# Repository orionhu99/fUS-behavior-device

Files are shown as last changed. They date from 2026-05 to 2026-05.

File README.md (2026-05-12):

# Head-fixed fUS behavior device control

整合式头部固定小鼠行为实验控制装置，兼容单光子/双光子/fUS 成像。

核心功能：
- **Cue-给水同步协议**：8kHz cue（PC 3.5mm 音响）+ 给水同时触发 → 2s 舔水窗 → 舔即记录 / 超时 MISS → 随机 ITI
- **电容舔水检测**（MPR121），直接寄存器读写，MDEBUG/THR 命令可调灵敏度
- **TTL 输出**：reward / lick / sync，对接成像采集系统
- **USB 摄像头录像 + 帧时间戳**，预览/录像独立切换，协议运行时自动录像
- **模块化水嘴支架**，预留食槽替换接口
- **PC 端 GUI**：参数设置、协议控制、时间轴舔水图表、事件日志

## File layout

```
arduino/
  water_lick_ttl_controller/water_lick_ttl_controller.ino  ← Water Nano 固件
  spout_motor_controller/spout_motor_controller.ino        ← Motor Nano 固件
  dianji/dianji.ino                                        ← 旧版电机测试（参考）
  sketch_apr25b/sketch_apr25b.ino                          ← 旧版给水测试（参考）
bpod/
  ExternalCueHiFi8kHz/ExternalCueHiFi8kHz.m                ← Bpod HiFi cue 协议
python/
  device_control_app.py     ← 主应用入口
  protocol_engine.py        ← 试次状态机
  gui_panels.py             ← GUI 面板组件
  lick_plot.py              ← matplotlib 舔水时间线
  config_manager.py         ← 协议配置 JSON 读写
  requirements.txt
  protocol_configs/         ← 保存的协议配置文件
      default.json
*.SLDPRT / *.STL / *.STEP  ← 3D 打印模型文件
```

## 给水协议

### 流程

```
IDLE → (▶ 运行) → ITI → PRECUE(200ms) → CUE(80ms, 8kHz) → 舔水窗口(3s)
                                                               ├─ 舔水 → 立即给水(400ms) → POST_REWARD(500ms) → ITI
                                                               └─ 超时 → 跳过(MISS) → ITI
```

- **Cue**：Water Nano D11 脉冲 TTL → Bpod BNC1 → HiFi 模块播放 8kHz tone
- **舔水窗口**：Nano 收到 `WINDOW dur reward` 命令后自治执行——监测 MPR121，舔到立即开泵，超时则跳过
- 关键延迟路径（舔→给水）在 Nano 上本地完成，不经 USB

### 可调参数

| 参数 | 默认值 | 说明 |
|---|---|---|
| `cue_duration_ms` | 80 | 8kHz 声音时长 |
| `precue_ms` | 200 | cue 前静默期（设 0 跳过） |
| `window_duration_ms` | 3000 | 舔水检测时间窗 |
| `reward_dose_ms` | 400 | 泵运行时长 |
| `post_reward_ms` | 500 | 给水后消耗期 |
| `iti_min_s` / `iti_max_s` | 20 / 60 | ITI 均匀随机范围 |
| `max_trials` | 200 | 最大试次数（0=不限） |
| `session_timeout_s` | 3600 | 最长会话时长 |

所有参数通过 GUI 调整，可保存/加载为 JSON 配置文件。

---

## Serial commands

### Water Nano

```
WATER [ms]           → 手动给水（含 reward TTL + cue TTL）
DOSE ms              → 设定默认剂量
PUMP ON / OFF        → 泵持续开/关
STOP                 → 停止泵 + 取消窗口模式
TTLMS ms             → 设定 TTL 脉宽
SYNCMS ms            → 设定同步脉冲间隔
CUE                  → 仅脉冲 D11 cue TTL（不启动泵）
WINDOW dur reward    → 启动舔水自治窗口（dur=窗口时长ms, reward=给水量ms）
WINDOW_STOP          → 取消当前窗口
STATUS / HELP
```

### Motor Nano（不变）

```
STEP signed_steps    GOTO position       F / B
JOG F / JOG B        STOP
ENABLE / DISABLE     SPEED microseconds
ZERO                 STATUS / HELP
```

---

## 接线（完整）

---

### 系统接线总览

```
┌─────────────────────────────────────────────────────────────────────────┐
│                               PC (USB Hub)                              │
│  USB1: Water Nano  │  USB2: Motor Nano  │  USB3: Bpod  │  USB4: 摄像头  │
└────┬──────────┬────┴──────────┬─────────┴──────┬───────┴──────┬────────┘
     │          │               │                │              │
┌────▼──┐  ┌────▼──────────┐  ┌▼─────────┐  ┌───▼──────┐  ┌───▼───┐
│ Water │  │   Motor Nano  │  │   Bpod   │  │  USB 摄  │  │ 水瓶  │
│ Nano  │  │               │  │  + HiFi  │  │  像头   │  │       │
│       │  │               │  │          │  │          │  │   │   │
│ D2─按钮│  │ D2─STEP─驱动板│  │ BNC1◄───┼──┼─D11(Cue) │  │   │   │
│ D3─LED │  │ D3─DIR──驱动板│  │     ┌───┼──┼─D8 (Rew) │  │   │   │
│ D5─MOS─┼──┼─蠕动泵       │  │ HiFi┼音响│  │ D9 (Lick)│  │  硅胶管─┤
│ D8─BNC─┼──┼─成像系统     │  │     │   │  │ D10(Sync)│  │       │   │
│ D9─BNC─┼──┼─成像系统     │  │     │   │  │          │  │   ┌───▼──┐│
│ D10─BNC┼──┼─成像系统     │  └─────┘   │  └──────────┘  │   │蠕动泵││
│ D11────┼──┼─Bpod BNC1   │            │               │   └──┬───┘│
│ A4─SDA─┼──┼─MPR121      │            │               │      │    │
│ A5─SCL─┼──┼─MPR121      │            │               │  外部电源 │
│        │  │             │            │               └──────────┘
│ 3V3/GND│  │ D4─ENA─驱动板│
│   ┤    │  │             │          ┌──────────────┐
│ MPR121 │  │ 5V/GND──驱动板│          │ 成像采集系统  │
│  E0    │  │             │          │ BNC Inputs:  │
│  ┤     │  │ 电机电源──驱动板│          │  Rew  Lick  │
│ 舔水管 │  │ 电机A/B──步进电机│         │  Sync Cue   │
└────────┘  └──────┬──────┘          └──────────────┘
                   │
              ┌────▼────┐
              │ 步进电机 │
              │ + 滑台  │
              └────┬────┘
                   │
              ┌────▼────┐
              │ 水嘴支架 │
              │(模块化) │
              └─────────┘
```

---

### 一、Water Nano 接线

Water Nano 是主控，负责蠕动泵、舔水检测、所有 TTL 输出。**在 Arduino IDE 中刷入 `arduino/water_lick_ttl_controller/` 固件。**

#### 1.1 引脚全表

| Nano 引脚 | 方向 | 连接到 | 线材 | 备注 |
|---|---|---|---|---|
| **D2** | 输入 (INPUT_PULLUP) | 轻触按钮一端，按钮另一端接 GND | 杜邦线 2P | 手动触发给水 |
| **D3** | 输出 | LED 正极（串 220Ω 电阻），LED 负极接 GND | 杜邦线 | 泵运行指示 |
| **D5** | 输出 | 三极管基极（串 1kΩ 电阻）或 MOSFET SIG 端 | 杜邦线 | 泵开关信号（HIGH=开） |
| **D8** | 输出 | BNC 母座中心针（Reward TTL） | 屏蔽线/杜邦线 | → 成像采集系统 |
| **D9** | 输出 | BNC 母座中心针（Lick TTL） | 屏蔽线/杜邦线 | → 成像采集系统 |
| **D10** | 输出 | BNC 母座中心针（Sync TTL） | 屏蔽线/杜邦线 | → 成像采集系统 |
| **D11** | 输出 | Bpod BNC1 中心针 | 屏蔽线/杜邦线 | Cue TTL → Bpod |
| **A4 / SDA** | I2C | MPR121 SDA 引脚 | 杜邦线母-母 | I2C 数据 |
| **A5 / SCL** | I2C | MPR121 SCL 引脚 | 杜邦线母-母 | I2C 时钟 |
| **5V** | 电源输出 | MPR121 VIN（若用 5V 供电版本） | 杜邦线 | 或接 3.3V |
| **3.3V** | 电源输出 | MPR121 VCC（推荐） | 杜邦线 | 噪声更小 |
| **GND** | 共地 | **所有以下设备的 GND**：MPR121、MOSFET 模块、BNC 外壳、Bpod GND | 多股杜邦线 | **最关键的单根线** |
| **VIN / USB** | 电源输入 | PC USB 口（供电 + 串口通信） | USB Mini-B 线 | 直接用 USB 供电即可 |

#### 1.2 手动按钮接线

```
Nano D2 ────┬──── 轻触按钮 ──── GND
            │
        (内部 INPUT_PULLUP，无需外接上拉电阻)
```

线序：D2 → 按钮一脚，按钮另一脚 → Nano GND。按下时 D2 读到 LOW，松开读到 HIGH。

#### 1.3 状态 LED 接线

```
Nano D3 ──── 220Ω 电阻 ──── LED 正极（长脚）
LED 负极（短脚） ──── Nano GND
```

#### 1.4 蠕动泵驱动 —— 方式 A：NPN 三极管（推荐，简单可靠）

```
        5V ───────────── 蠕动泵 +
        Nano D5 ── 1kΩ ── 三极管 Base (如 S8050 / 2N2222)
        蠕动泵 - ──────── 三极管 Collector
        Nano GND ─────── 三极管 Emitter

        三极管引脚（TO-92 封装，平面朝自己，脚朝下）：
                  ┌─────┐
        Collector │  ·  │  ← 接泵-
           Base   │  ·  │  ← 接 1kΩ → D5
         Emitter  │  ·  │  ← 接 GND
                  └─────┘
```

- D5 HIGH → 三极管导通 → 泵运转
- D5 LOW → 三极管截止 → 泵停止
- 泵两端反向并联一个 1N4007 续流二极管（带环一端接泵+，另一端接泵-），防止关断时反向电压击穿三极管
- 三极管选型：泵电流 < 500mA 用 S8050 即可；更大电流用 TIP120 达林顿管

#### 1.4 蠕动泵驱动 —— 方式 B：MOSFET 模块

```
┌─────────────┐
│  外部电源    │      注意：泵的电压/电流不要超过
│  (如 12V)   │      MOSFET 模块的额定值
│  +      -   │
│  │      │   │
│  │      └───┼──────────────┐
│  │          │              │
│  │    ┌─────▼──────┐      │
│  │    │ MOSFET 模块 │      │
│  │    │  DC+   DC- │      │
│  │    │  IN   GND  │      │
│  │    │  OUT+ OUT- │      │
│  │    └──┬───┬──┬──┘      │
│  │       │   │  │         │
│  └───────┼───┘  │         │
│          │      │         │
│    ┌─────▼──────┼──┐      │
│    │  蠕动泵     │  │      │
│    │   +    -   │  │      │
│    │   │    │   │  │      │
│    │   │    └───┼──┘      │
│    │   │        │         │
│    └───┼────────┘         │
│        │                  │
└────────┘                  │
                            │
    Nano D5 ──── IN         │
    Nano GND ─── GND ───────┘
```

接线步骤：
1. 外部电源 + 接 MOSFET 模块 DC+
2. 外部电源 - 接 MOSFET 模块 DC-
3. 蠕动泵 + 接 MOSFET 模块 OUT+
4. 蠕动泵 - 接 MOSFET 模块 OUT-
5. Nano D5 接 MOSFET 模块 IN（信号输入端）
6. **Nano GND 接 MOSFET 模块 GND（必须共地）**

> ⚠️ 泵是感性负载，关断时会产生反向电动势。如果 MOSFET 模块不带保护二极管，在泵两端并联一个续流二极管（如 1N4007）：阴极（带环一端）接泵+，阳极接泵-。

---

### 二、MPR121 电容舔水检测接线

#### 2.1 MPR121 → Water Nano

```
MPR121 VCC  ──── Nano 3.3V  （推荐 3.3V，噪声更低）
MPR121 GND  ──── Nano GND
MPR121 SDA  ──── Nano A4
MPR121 SCL  ──── Nano A5
MPR121 ADD  ──── 不接（默认 I2C 地址 0x5A）
MPR121 IRQ  ──── 不接（固件用轮询方式）
MPR121 E0   ──── 金属舔水管（见下方隔离说明）
```

#### 2.2 MPR121 电极隔离（最关键！）

```
┌──────────────────────────────────────────────────┐
│                  3D 打印支架                      │
│                                                  │
│   ┌──────────────────────────────┐              │
│   │  PTFE 绝缘套管（包住水管）     │              │
│   │  ┌────────────────────┐      │              │
│   │  │  金属舔水管（不锈钢）│      │              │
│   │  │  █████████████████ │      │              │
│   │  │  █████████████████ │      │              │
│   │  └──────────┬─────────┘      │              │
│   │             │ 仅管尖 1−2mm    │              │
│   │             │ 暴露供舔舐      │              │
│   └─────────────┼────────────────┘              │
│                 │                                │
│       MPR121 E0 ┘  (焊接或屏蔽线夹紧)              │
│                                                  │
│   水管全程不得与支架/电机/Z台/平台有金属接触        │
└──────────────────────────────────────────────────┘
```

操作步骤：
1. 截一段 PTFE 管（外径略小于支架孔），长度略长于支架厚度
2. 将 PTFE 管套在不锈钢水管外面，穿过 3D 打印支架孔
3. 不锈钢水管管体包覆热缩管，加热收缩，仅留管尖 1-2mm 裸露
4. MPR121 E0 引脚焊接一段细导线（或屏蔽线内芯），另一端用导电胶/焊锡/鳄鱼夹连接到不锈钢水管
5. 用万用表电阻档确认：水管与光学平台/电机外壳/支架之间的电阻 > 10MΩ（无穷大）

> 如果漏电（水管和大地导通），MPR121 会读到大量噪声，舔水检测失效。**这步做不好，整个系统不能用。**

---

### 三、Motor Nano 接线

Motor Nano 控制安装在手动 Z 台上的步进电机，用于微调水嘴位置。**在 Arduino IDE 中刷入 `arduino/spout_motor_controller/` 固件。**

#### 3.1 引脚全表

| Nano 引脚 | 方向 | 连接到 | 线材 | 备注 |
|---|---|---|---|---|
| **D2** | 输出 | 驱动板 STEP- (或 PUL-) | 杜邦线 | 步进脉冲 |
| **D3** | 输出 | 驱动板 DIR- | 杜邦线 | 方向信号 |
| **D4** | 输出 | 驱动板 ENA- | 杜邦线 | 使能（低电平有效） |
| **5V** | 电源输出 | 驱动板 STEP+/DIR+/ENA+ | 杜邦线 3 根 | **仅光耦驱动板需此接法** |
| **GND** | 共地 | 驱动板信号 GND（如有） | 杜邦线 | 非光耦驱动板需共地 |
| **VIN / USB** | 电源输入 | PC USB 口（供电 + 串口通信） | USB Mini-B 线 | |

#### 3.2 步进电机驱动板接线 —— 方式 A：光耦输入驱动板（如 TB6600 / DM542 / DM556）

这些驱动板的信号输入是光耦隔离的，推荐**共阳极接法**：

```
        Nano 5V ───┬─── 驱动板 PUL+  ┐
                    ├─── 驱动板 DIR+   │ 三个正端全部接 Nano 5V
                    └─── 驱动板 ENA+  ┘

        Nano D2 ─────── 驱动板 PUL-
        Nano D3 ─────── 驱动板 DIR-
        Nano D4 ─────── 驱动板 ENA-

        外部电源 + ───── 驱动板 VCC（电机电源输入，如 24V）
        外部电源 - ───── 驱动板 GND

        驱动板 A+ ────── 步进电机 A+（通常红色）
        驱动板 A- ────── 步进电机 A-（通常蓝色）
        驱动板 B+ ────── 步进电机 B+（通常绿色）
        驱动板 B- ────── 步进电机 B-（通常黑色）
```

> 注意：共阳接法时 Nano GND **不需要**接驱动板信号 GND。驱动板的信号地和功率地通常内部隔离。

#### 3.3 步进电机驱动板接线 —— 方式 B：普通逻辑输入驱动板（如 A4988 / DRV8825 / TMC2208）

```
        驱动板 VDD  ───── Nano 5V
        驱动板 GND  ───── Nano GND

        驱动板 STEP ───── Nano D2
        驱动板 DIR  ───── Nano D3
        驱动板 ENABLE ─── Nano D4

        驱动板 VMOT ───── 外部电源 +
        驱动板 GND  ───── 外部电源 -

        驱动板 1A ─────── 步进电机 A+
        驱动板 1B ─────── 步进电机 A-
        驱动板 2A ─────── 步进电机 B+
        驱动板 2B ─────── 步进电机 B-
```

> 固件默认 `enableActiveLow = true`。如果你的驱动板是高电平使能（如某些 TMC 系列），打开 `.ino` 文件把第 8 行改成 `const bool enableActiveLow = false;`。

---

### 四、TTL 信号输出接线

Water Nano 的 D8/D9/D10/D11 输出 5V TTL 脉冲。需要接到成像系统或用 BNC 接口标准化。

#### 4.1 TTL → BNC 母座（接成像系统）

自制 BNC 转接线（每路 TTL 做一根）：

```
Nano D8/D9/D10/D11 ──────── BNC 母座中心针（信号）
Nano GND           ──────── BNC 母座外壳/屏蔽层（地）
```

做法：
1. 取一段同轴电缆或双绞屏蔽线
2. 内芯一端接 Nano 排针（用杜邦母头压接或焊接），另一端焊 BNC 母座中心针
3. 屏蔽层一端接 Nano GND，另一端焊 BNC 母座外壳
4. BNC 母座固定在 3D 打印面板或铝盒上，用 BNC 公-公线连到成像系统

#### 4.2 TTL 信号分工

| Nano 引脚 | 事件 | 脉冲宽度 | 目标设备 |
|---|---|---|---|
| **D8** | Reward（给水开始） | `ttlPulseMs` (默认 10ms) | 成像系统 AI 通道 1 |
| **D9** | Lick（舔水） | `ttlPulseMs` (默认 10ms) | 成像系统 AI 通道 2 |
| **D10** | Sync（同步） | `ttlPulseMs` (默认 10ms) | 成像系统 AI 通道 3 |
| **D11** | Cue（8kHz 触发） | `ttlPulseMs` (默认 10ms) | Bpod BNC1 输入 |

> 成像系统如果是 BNC 接口，直接对接。如果是 DAQ 端子排（如 NI 68-Pin），做 BNC→端子排转接线。

#### 4.3 TTL 电平兼容性

- Nano 输出 5V TTL，兼容 3.3V 和 5V 逻辑
- Bpod r2/r2+ BNC 输入接受 3-5V TTL，光隔离，直接可接
- 如果目标设备只接受 3.3V：在信号线上串 1kΩ 限流电阻 + 对地接 3.3V 稳压管

---

### 五、Bpod + HiFi 模块接线

#### 5.1 Bpod → PC

```
Bpod USB-B ──── PC USB 口（供电 + MATLAB 通信）
```

#### 5.2 HiFi 模块 → Bpod

```
HiFi 模块 ──── Bpod 机箱背面模块接口（通过扁平排线或专用接口）
```

> 在 Bpod Console GUI 中确认模块识别为 `HiFi1`，USB 端口号写入 `BpodSystem.ModuleUSB.HiFi1`。

#### 5.3 HiFi 模块 → 音响

```
HiFi 模块音频输出 (3.5mm 或 RCA) ──── 有源音箱 Line In
```

> 使用有源音箱（自带功放）。如果只有无源音箱，中间需要加功放模块。HiFi 模块输出是线路电平，直接推不动无源音箱。

#### 5.4 Bpod BNC1 输入 ← Water Nano Cue TTL

```
Water Nano D11 ──── BNC 中心针 ──── Bpod BNC1 输入
Water Nano GND ──── BNC 外壳     ──── Bpod GND（如 BNC 外壳已内部接地则不必额外接）
```

#### 5.5 运行 Bpod 端

在 MATLAB 中：
```matlab
cd('D:\Research\fUS\device\bpod\ExternalCueHiFi8kHz')
ExternalCueHiFi8kHz
```

Bpod 会进入等待状态，每次 Water Nano D11 发来 TTL 脉冲，HiFi 就播放 80ms 的 8kHz tone。

---

### 六、USB 摄像头接线

```
USB 摄像头 ──── PC USB 口
```

- 在 GUI "连接"面板中输入摄像头索引（通常是 `0`，如有多个摄像头试 `1`、`2`）
- 点击"开始录像"即开始录制并生成帧时间戳 CSV
- 摄像头对准小鼠侧面/正面，记录舔水和行为

---

### 七、PC 端最终连接汇总

| 设备 | 接口 | PC 端口 |
|---|---|---|
| Water Nano | USB Mini-B | USB 1 |
| Motor Nano | USB Mini-B | USB 2 |
| Bpod | USB-B | USB 3 |
| USB 摄像头 | USB-A | USB 4 |

> 建议用一个 **有源 USB 3.0 Hub**（4 口以上），固定在光学平台边缘，只出一根线到 PC。减少桌面杂乱。

---

### 八、电源分配

| 用电设备 | 供电方式 | 电压 | 备注 |
|---|---|---|---|
| Water Nano | PC USB | 5V | 同时通信 |
| Motor Nano | PC USB | 5V | 同时通信 |
| MPR121 | Water Nano 3.3V | 3.3V | Nano 直接供电 |
| 蠕动泵 | 外部电源 → MOSFET | 12V（视泵规格） | **不要从 Nano 取电** |
| 步进电机 | 外部电源 → 驱动板 | 12-24V（视电机/驱动板） | **不要从 Nano 取电** |
| 步进驱动板逻辑 | Nano 5V（光耦型） | 5V | 电流很小 |
| Bpod | 自带电源适配器 | — | 官配 |
| 有源音箱 | 自带电源/USB | — | |

> 建议用一个双路输出开关电源（如 24V/12V 双路），或两个独立电源适配器分别给蠕动泵和步进电机供电。

---

### 九、上电顺序

1. 检查所有接线（特别确认：泵和电机的供电**没有**接到 Nano）
2. MPR121 隔离用万用表确认（水管对地电阻无穷大）
3. 打开蠕动泵和步进电机的外部电源
4. 打开 Bpod 电源
5. 所有 USB 插入 PC（或 USB Hub 上电）
6. 打开有源音箱，音量调至适中
7. 在 Arduino IDE 中确认两个 Nano 都识别到正确的 COM 口
8. 启动 Bpod MATLAB 协议 `ExternalCueHiFi8kHz`
9. 启动 Python GUI `python python\device_control_app.py`
10. 在 GUI 中依次连接 Water Nano 和 Motor Nano
11. 连接成功后，先用手动模式测试：手动给水确认泵和 TTL 正常，电机微调确认运动正常
12. 一切正常后，加载协议配置，点击 ▶ 运行

---

### 十、接地策略

```
                    ┌─── 光学平台（金属）─── 接大地（如有）
                    │
    ┌───────────────┼────────────────────────┐
    │               │                        │
    │  Water Nano GND ─┬─ MPR121 GND         │
    │                  ├─ MOSFET 模块 GND     │
    │                  ├─ BNC 外壳 (x4)      │
    │                  └─ Bpod BNC 外壳      │
    │                                        │
    │  Motor Nano GND ─── 驱动板信号 GND      │
    │  （光耦型驱动板则无需）                  │
    │                                        │
    │  外部电源 - ──┬─ MOSFET DC-            │
    │              └─ 驱动板功率 GND          │
    │                                        │
    │  所有设备通过 USB 电缆屏蔽层在 PC 端单点共地 │
    └────────────────────────────────────────┘
```

> 接地原则：所有信号 GND（Nano、MPR121、MOSFET 信号侧、TTL 目标设备）必须连通。不要形成地环路——在 PC USB 端单点汇聚即可。如果出现 50Hz 工频干扰在 MPR121 上，检查是否有多点接地。

---

## PC 端使用

### 安装

```powershell
pip install -r python\requirements.txt
```

### 运行

```powershell
python python\device_control_app.py
```

### GUI 面板

| 面板 | 功能 |
|---|---|
| 连接 | COM 端口选择、Nano 连接、摄像头控制、输出目录 |
| 手动控制 | 剂量设定、手动给水、泵开关、TTL/同步参数、PC 测试音 |
| 电机控制 | 大小步进微调、速度设定、归零 |
| 协议控制 | 全部协议参数、运行/暂停/停止、配置保存加载、状态显示 |
| 舔水时间线 | 实时试次栅格图 + 累积直方图 |
| 事件日志 | 所有串口事件 + 主机时间戳 |

### 输出文件

```
recordings/
  device_events_*.csv        ← 全事件日志（串口 + 主机）
  behavior_*.avi             ← 摄像头视频
  behavior_*_frames.csv      ← 视频帧时间戳
```

---

## 8kHz Cue 声音

**主方案**：PC 3.5mm 音频口 → 有源音箱。协议进入 CUE 阶段时自动播放 8kHz 纯音（WAV 生成 + winsound 播放），无需 Bpod/HiFi 模块。

手动测试：GUI "手动控制" 面板勾选 "PC 8kHz"，点"给水"时同步播放 cue 音。

> 如需 Bpod/HiFi 方案（更低延迟），D11 cue TTL 仍然保留，可接 Bpod BNC1 输入，运行 `bpod/ExternalCueHiFi8kHz/ExternalCueHiFi8kHz.m`。PC 音频和 TTL cue 可同时工作互不冲突。

---

## 时间对齐

**推荐方案：纯 USB 软件时间戳（±5ms，一帧以内）**

events.csv 中每条事件和 video_frames.csv 中每帧都有 `host_monotonic_s`（`time.perf_counter()`），两者统一时间轴对齐。

数据目录结构：
```
data/20260512_143000/
  events.csv          ← 所有事件 + host_monotonic_s
  video.avi           ← 摄像头录像
  video_frames.csv    ← 每帧时间戳
  session.json        ← 协议参数 + 试次汇总
```

**可选方案：物理 TTL 同步**

如需硬件级同步，Nano D8( Reward ) / D9( Lick ) / D10( Sync ) 通过 BNC 接入成像系统数字输入。Sync 每 5s 脉冲一次。

---

## 3D 打印件

| 零件 | 文件 | 说明 |
|---|---|---|
| 散热风扇导管 | `tube-fan3.0-4.3.STL` | |
| 动物固定兜 | `兜子.STEP` | 头部固定小鼠 |
| 给水外壳 | `给水1.0外壳.SLDPRT` | 电子盒外壳 |
| 水嘴模块底板（待设计） | — | 安装于电机滑台，带燕尾槽快拆接口 |
| 水嘴支架模块（待设计） | — | PTFE 绝缘套管、可调角度、快拆锁紧 |
| 食槽模块（预留接口） | — | 同底板燕尾槽规格 |

---

## 硬件清单

| 组件 | 说明 |
|---|---|
| PC (Windows) | USB 接口 ×4+ |
| Arduino Nano ×2 | Water + Motor |
| MPR121 电容模块 | I2C 接口，Adafruit 库 |
| 蠕动泵 + MOSFET 驱动 | 外部电源供电 |
| 步进电机 + 驱动板 | TB6600/DM 系列 |
| 手动 Z 台 + 电机滑台 | 水嘴微调 |
| 有源音箱 | PC 3.5mm 音频口连接 |
| Bpod + HiFi 模块（可选） | 低延迟 cue 播放备选 |
| USB 摄像头 | OpenCV 兼容 |
| 光学平台 | 面包板，M6 或 1/4"-20 孔距 |
| 3D 打印件 | 如上表 |
| 金属舔水管 | 不锈钢，与支架绝缘 |
| PTFE 管 / 热缩管 | MPR121 隔离 |
| BNC 线 / 杜邦线 | TTL 连接 |
| 硅胶管 / 水瓶 | 水路 |

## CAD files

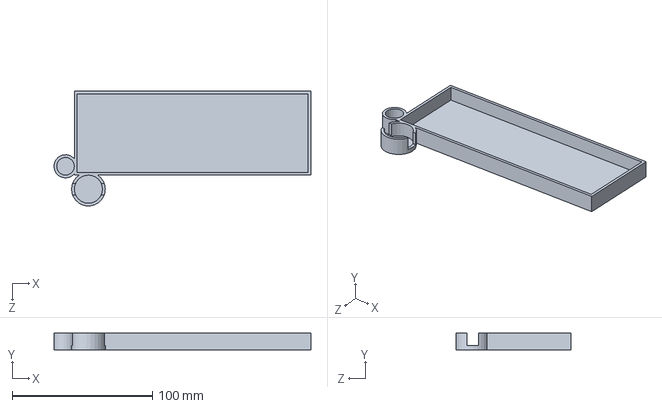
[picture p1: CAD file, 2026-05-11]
给水1.0外壳.SLDPRT
183.5 x 12.0 x 82.0 mm

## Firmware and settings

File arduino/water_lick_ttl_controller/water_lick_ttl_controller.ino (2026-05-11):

#include <Wire.h>
#include <avr/wdt.h>

// Nano for water delivery, lick detection, and TTL event outputs.

const byte buttonPin = 2;
const byte ledPin = 3;
const byte pumpPin = 5;

const byte rewardTtlPin = 8;
const byte lickTtlPin = 9;
const byte syncTtlPin = 10;
const byte cueTtlPin = 11;

const byte lickElectrode = 0;

// ── 参数 ──
unsigned long doseMs = 400;
unsigned long ttlPulseMs = 10;
unsigned long lickRefractoryMs = 100;
unsigned long syncIntervalMs = 5000;

// ── MPR121 灵敏度（运行时可调）──
byte mprTouchThr = 8;     // 触摸阈值，越小越灵敏（范围 1-255，默认 12）
byte mprReleaseThr = 4;   // 释放阈值，应小于触摸阈值（默认 6）
int confirmDeltaMin = 5;  // 软件确认：abs(baseline-filtered) 最小变化量

// ── 状态 ──
bool pumpRunning = false;
bool autoMode = false;

// MPR121
byte mprAddr = 0x5A;
bool mpr121Ready = false;

// 舔水检测
bool lastTouched = false;
bool lickLatched = false;
unsigned long lastLickAt = 0;
unsigned long lastReleaseAt = 0;
unsigned long lickReleaseMs = 100;
int confirmCnt = 0;

// 窗口模式
bool windowMode = false;
unsigned long windowStartAt = 0;
unsigned long windowDurationMs = 0;
unsigned long windowRewardMs = 0;
bool windowRewarded = false;

// 计时
unsigned long pumpStopAt = 0;
unsigned long nextSyncAt = 0;
unsigned long rewardTtlOffAt = 0;
unsigned long lickTtlOffAt = 0;
unsigned long syncTtlOffAt = 0;
unsigned long cueTtlOffAt = 0;

char line[64];
byte lineIdx = 0;

// ═══════════════════════════════════════════════════════════
// MPR121 底层读写（绕过 Adafruit 库）
// ═══════════════════════════════════════════════════════════

static unsigned long lastMprRead = 0;
static bool i2cOk = true;

bool mprWrite(byte reg, byte val) {
  Wire.beginTransmission(mprAddr);
  Wire.write(reg);
  Wire.write(val);
  byte r = Wire.endTransmission();
  if (r != 0) { i2cOk = false; return false; }
  i2cOk = true; return true;
}

byte mprRead8(byte reg) {
  Wire.beginTransmission(mprAddr);
  Wire.write(reg);
  if (Wire.endTransmission(false) != 0) { i2cOk = false; return 0; }
  Wire.requestFrom((uint8_t)mprAddr, (uint8_t)1);
  byte v = Wire.available() ? Wire.read() : 0;
  i2cOk = true; return v;
}

uint16_t mprRead16(byte reg) {
  Wire.beginTransmission(mprAddr);
  Wire.write(reg);
  if (Wire.endTransmission(false) != 0) { i2cOk = false; return 0; }
  Wire.requestFrom((uint8_t)mprAddr, (uint8_t)2);
  uint16_t v = 0;
  if (Wire.available()) v = Wire.read();
  if (Wire.available()) v |= ((uint16_t)Wire.read() << 8);
  i2cOk = true; return v & 0x03FF;
}

void i2cRecover() {
  Wire.end();
  delay(5);
  Wire.begin();
  delay(5);
  i2cOk = true;
}

// ═══════════════════════════════════════════════════════════
// MPR121 手动初始化（不依赖 Adafruit 库的 begin）
// ═══════════════════════════════════════════════════════════

bool initMpr121() {
  Serial.println(F("--- MPR121 manual init ---"));

  // 1. I2C 扫描
  Serial.println(F("I2C scan:"));
  int found = 0;
  for (byte a = 1; a < 127; a++) {
    Wire.beginTransmission(a);
    if (Wire.endTransmission() == 0) {
      Serial.print(F("  0x")); Serial.println(a, HEX);
      found++;
    }
  }
  if (found == 0) {
    Serial.println(F("!! No I2C devices — check VCC/GND/SDA/SCL wiring"));
    return false;
  }

  // 2. 尝试 MPR121 地址
  byte addrs[] = {0x5A, 0x5B, 0x5C, 0x5D};
  mprAddr = 0;
  for (byte i = 0; i < 4; i++) {
    Wire.beginTransmission(addrs[i]);
    if (Wire.endTransmission() == 0) { mprAddr = addrs[i]; break; }
  }
  if (mprAddr == 0) {
    Serial.println(F("!! MPR121 not found at 0x5A-0x5D"));
    return false;
  }
  Serial.print(F("MPR121 at 0x")); Serial.println(mprAddr, HEX);

  // 3. 软复位
  mprWrite(0x80, 0x63);
  delay(10);

  // 4. 停止，开始配置
  mprWrite(0x5E, 0x00);
  delay(5);

  // 5. AFE 配置（Analog Front End）
  mprWrite(0x2B, 0x01); // MHD Rising
  mprWrite(0x2C, 0x01); // NHD Rising
  mprWrite(0x2D, 0x00); // NCL Rising
  mprWrite(0x2E, 0x00); // FDL Rising
  mprWrite(0x2F, 0x01); // MHD Falling
  mprWrite(0x30, 0x01); // NHD Falling
  mprWrite(0x31, 0xFF); // NCL Falling
  mprWrite(0x32, 0x02); // FDL Falling

  // 6. 触摸/释放阈值 — 只设电极 0
  mprWrite(0x41, mprTouchThr);   // E0 触摸阈值
  mprWrite(0x42, mprReleaseThr); // E0 释放阈值

  // 7. 去抖
  mprWrite(0x5B, 0x00); // 去抖 = 0（由软件处理）

  // 8. 配置寄存器
  mprWrite(0x5C, 0x10); // Config1: FFI=1 (28ms 首滤波), CDC=0, SFI=0, ESI=0
  mprWrite(0x5D, 0x20); // Config2: 0.5uA 充电, 0.5us 充电时间

  // 9. 使能电极 0（仅 E0，开启基线自动追踪）
  //    ECR bit[3:0] = 电即使能 + 基线追踪
  //    ECR bit[7:4] = 接近检测使能（不用）
  mprWrite(0x5E, 0x01);

  delay(200);

  // 10. 校验：回读 ECR
  byte ecr = mprRead8(0x5E);
  Serial.print(F("ECR = 0x")); Serial.println(ecr, HEX);
  if (ecr != 0x01) {
    Serial.println(F("!! ECR mismatch — configuration failed"));
    return false;
  }

  // 11. 读初始值
  uint16_t f0 = mprRead16(0x04);
  uint16_t b0 = mprRead16(0x1E);
  Serial.print(F("E0 raw filtered=")); Serial.print(f0);
  Serial.print(F(" baseline=")); Serial.print(b0);
  Serial.print(F(" diff=")); Serial.println((int16_t)b0 - (int16_t)f0);

  if (f0 == 0 && b0 == 0) {
    Serial.println("!! filtered=0 AND baseline=0 -- electrode may be floating");
    Serial.println("   Check: MPR121 E0 pin -> metal lick tube");
    Serial.println("   Check: tube insulation with multimeter");
  }

  Serial.println(F("--- MPR121 init done ---"));
  Serial.println("Send MDEBUG for live values, REGDUMP for register dump");
  return true;
}

// ═══════════════════════════════════════════════════
// 初始化
// ═══════════════════════════════════════════════════

void setup() {
  pinMode(buttonPin, INPUT_PULLUP);
  pinMode(ledPin, OUTPUT);
  pinMode(pumpPin, OUTPUT);
  pinMode(rewardTtlPin, OUTPUT);
  pinMode(lickTtlPin, OUTPUT);
  pinMode(syncTtlPin, OUTPUT);
  pinMode(cueTtlPin, OUTPUT);

  setPump(false);
  setAllTtlsLow();

  Serial.begin(115200);
  while (!Serial) {}

  // 看门狗：500ms 超时自动复位（防止 I2C 卡死导致永久死机）
  wdt_enable(WDTO_500MS);

  mpr121Ready = initMpr121();

  logEvent("READY", mpr121Ready ? "MPR121_OK" : "MPR121_MISSING");
  printHelp();
}

// ═══════════════════════════════════════════════════
// 主循环
// ═══════════════════════════════════════════════════

void loop() {
  wdt_reset();  // 喂狗
  const unsigned long now = millis();
  readSerial();
  readButton();
  readLick(now);
  updatePump(now);
  updateTtls(now);
  updateSync(now);
  updateWindow(now);
}

// ═══════════════════════════════════════════════════
// 串口命令
// ═══════════════════════════════════════════════════

void readSerial() {
  while (Serial.available() > 0) {
    char c = (char)Serial.read();
    if (c == '\n' || c == '\r') {
      if (lineIdx > 0) {
        line[lineIdx] = '\0';
        handleCommand(line);
        lineIdx = 0;
      }
    } else if (lineIdx < 63) {
      line[lineIdx++] = c;
    }
  }
}

void handleCommand(const char* cmd) {
  // 跳过前导空格
  while (*cmd == ' ' || *cmd == '\t') cmd++;
  int len = strlen(cmd);
  if (len == 0) return;

  // 转大写
  char upper[64];
  for (int i = 0; i <= len; i++) upper[i] = (cmd[i] >= 'a' && cmd[i] <= 'z') ? cmd[i] - 32 : cmd[i];

  if (strcmp(upper, "HELP") == 0)             printHelp();
  else if (strcmp(upper, "STATUS") == 0)      logEvent("STATUS", statusText());
  else if (strcmp(upper, "WATER") == 0)       startDose(doseMs);
  else if (strncmp(upper, "WATER ", 6) == 0)  startDose(atol(upper + 6));
  else if (strncmp(upper, "DOSE ", 5) == 0)   { doseMs = atol(upper + 5); logEvent("DOSE_MS", String(doseMs).c_str()); }
  else if (strcmp(upper, "PUMP ON") == 0)     { autoMode = true;  setPump(true);  logEvent("PUMP", "ON"); }
  else if (strcmp(upper, "PUMP OFF") == 0 || strcmp(upper, "STOP") == 0) {
    autoMode = false; pumpRunning = false; windowMode = false;
    setPump(false); logEvent("PUMP", "OFF");
  }
  else if (strcmp(upper, "CUE") == 0)         { pulseCueTtl(millis()); logEvent("CUE", "1"); }
  else if (strncmp(upper, "WINDOW ", 7) == 0) {
    char* sp1 = strchr(upper + 7, ' ');
    if (sp1) {
      windowDurationMs = atol(upper + 7);
      windowRewardMs = atol(sp1 + 1);
      windowMode = true; windowStartAt = millis(); windowRewarded = false;
      logEvent("WINDOW_START", (String(windowDurationMs) + "," + String(windowRewardMs)).c_str());
    }
  }
  else if (strcmp(upper, "WINDOW_STOP") == 0) { windowMode = false; logEvent("WINDOW_STOP", "0"); }
  else if (strncmp(upper, "TTLMS ", 6) == 0)  { ttlPulseMs = atol(upper + 6); logEvent("TTL_MS", String(ttlPulseMs).c_str()); }
  else if (strncmp(upper, "SYNCMS ", 7) == 0) { syncIntervalMs = atol(upper + 7); logEvent("SYNC_MS", String(syncIntervalMs).c_str()); }
  else if (strcmp(upper, "MDEBUG") == 0)      printMdebug();
  else if (strcmp(upper, "REGDUMP") == 0)     dumpRegisters();
  else if (strcmp(upper, "RESETMPR") == 0)    { mpr121Ready = initMpr121(); }
  else if (strncmp(upper, "THR ", 4) == 0) {
    char* sp = strchr(upper + 4, ' ');
    if (sp) {
      mprTouchThr = atoi(upper + 4);
      mprReleaseThr = atoi(sp + 1);
      mprWrite(0x41, mprTouchThr); mprWrite(0x42, mprReleaseThr);
      logEvent("THR", (String(mprTouchThr) + "," + String(mprReleaseThr)).c_str());
    }
  }
  else if (strncmp(upper, "DMIN ", 5) == 0)   { confirmDeltaMin = atoi(upper + 5); logEvent("DMIN", String(confirmDeltaMin).c_str()); }
  else                                         logEvent("ERR", "UNKNOWN_COMMAND");
}

// ── 诊断命令 ──

void printMdebug() {
  uint16_t f = mprRead16(0x04);
  uint16_t b = mprRead16(0x1E);
  uint8_t  t = mprRead8(0x00);
  int16_t diff = (int16_t)b - (int16_t)f;
  Serial.print(millis());
  Serial.print(F(",DEBUG,filtered=")); Serial.print(f);
  Serial.print(F(",baseline=")); Serial.print(b);
  Serial.print(F(",diff=")); Serial.print(diff);
  int16_t ad = (int16_t)b - (int16_t)f;
  if (ad < 0) ad = -ad;
  Serial.print(F(",touched=0x")); Serial.print(t, HEX);
  Serial.print(F(",thr=")); Serial.print(mprTouchThr);
  Serial.print(F(",dmin=")); Serial.println(ad >= confirmDeltaMin ? 1 : 0);
}

void dumpRegisters() {
  Serial.println(F("--- MPR121 register dump ---"));
  Serial.print(F("ECR(0x5E)=")); Serial.println(mprRead8(0x5E), HEX);
  Serial.print(F("CONF1(0x5C)=")); Serial.println(mprRead8(0x5C), HEX);
  Serial.print(F("CONF2(0x5D)=")); Serial.println(mprRead8(0x5D), HEX);
  Serial.print(F("TOUCH_STAT(0x00)=")); Serial.println(mprRead8(0x00), HEX);
  Serial.print(F("OOR_STAT(0x02)=")); Serial.println(mprRead8(0x02), HEX);
  Serial.print(F("E0_TOUCH_THR(0x41)=")); Serial.println(mprRead8(0x41));
  Serial.print(F("E0_REL_THR(0x42)=")); Serial.println(mprRead8(0x42));
  Serial.print(F("DEBOUNCE(0x5B)=")); Serial.println(mprRead8(0x5B), HEX);

  uint16_t f0 = mprRead16(0x04);
  uint16_t b0 = mprRead16(0x1E);
  Serial.print(F("E0 filtered=")); Serial.print(f0);
  Serial.print(F(" baseline=")); Serial.print(b0);
  Serial.print(F(" diff=")); Serial.println((int16_t)b0 - (int16_t)f0);

  // 读 CDC 原始计数（电极 0 的 CDC: 0x59-0x5A？）
  // 实际上是 0x04-0x05=filtered, 0x1E-0x1F=baseline
  Serial.println(F("--- end dump ---"));
}

// ═══════════════════════════════════════════════════
// 按钮
// ═══════════════════════════════════════════════════

void readButton() {
  static bool lastButton = HIGH;
  bool button = digitalRead(buttonPin);
  if (lastButton == HIGH && button == LOW) {
    startDose(doseMs);
  }
  lastButton = button;
}

// ═══════════════════════════════════════════════════
// 舔水检测
// ═══════════════════════════════════════════════════

void readLick(unsigned long now) {
  if (!mpr121Ready) return;

  // 降频：每 5ms 读一次（200Hz），防 I2C 总线风暴
  if (now - lastMprRead < 5) return;
  lastMprRead = now;

  // I2C 异常恢复
  if (!i2cOk) { i2cRecover(); return; }

  // 读 MPR121 寄存器（一次 3 字节批量读，减少 I2C 事务）
  uint8_t touchedReg = mprRead8(0x00);
  uint16_t filtered = mprRead16(0x04);
  uint16_t baseline = mprRead16(0x1E);
  if (!i2cOk) return;  // 本次读取失败则跳过

  bool hwTouched = touchedReg & 0x01;
  int16_t delta = (int16_t)baseline - (int16_t)filtered;
  int16_t adelta = delta < 0 ? -delta : delta;
  bool signalOk = adelta >= confirmDeltaMin;
  bool isTouched = hwTouched && signalOk;

  if (isTouched) confirmCnt++;
  else           confirmCnt = 0;
  bool confirmed = (confirmCnt >= 2);

  // 上升沿 → 触发舔水
  if (confirmed && !lastTouched && !lickLatched &&
      (now - lastLickAt >= lickRefractoryMs)) {
    lastLickAt = now;
    lickLatched = true;
    pulseLickTtl(now);
    logEvent("LICK", (String(lickElectrode)).c_str());
    if (windowMode && !windowRewarded) {
      startWindowReward(windowRewardMs);
      logEvent("WINDOW_LICK", (String(windowRewardMs)).c_str());
    }
  }

  // 释放检测
  if (!confirmed && lastTouched) lastReleaseAt = now;
  if (lickLatched && !confirmed && (now - lastReleaseAt >= lickReleaseMs))
    lickLatched = false;

  lastTouched = confirmed;
}

// ═══════════════════════════════════════════════════
// 给水
// ═══════════════════════════════════════════════════

void startDose(unsigned long ms) {
  if (ms == 0) return;
  unsigned long now = millis();
  autoMode = false;
  pumpRunning = true;
  pumpStopAt = now + ms;
  setPump(true);
  pulseRewardTtl(now);
  pulseCueTtl(now);
  logEvent("WATER", (String(ms)).c_str());
}

void startWindowReward(unsigned long ms) {
  if (ms == 0) return;
  unsigned long now = millis();
  windowRewarded = true;
  autoMode = false;
  pumpRunning = true;
  pumpStopAt = now + ms;
  setPump(true);
  pulseRewardTtl(now);
  logEvent("WINDOW_REWARD", (String(ms)).c_str());
}

// ═══════════════════════════════════════════════════
// 定时更新
// ═══════════════════════════════════════════════════

void updateWindow(unsigned long now) {
  if (!windowMode) return;
  if (!windowRewarded && timeReached(now, windowStartAt + windowDurationMs)) {
    windowMode = false; logEvent("WINDOW_END", "MISSED");
  }
  if (windowRewarded && !pumpRunning) {
    windowMode = false; logEvent("WINDOW_END", "REWARDED");
  }
}

void updatePump(unsigned long now) {
  if (pumpRunning && !autoMode && timeReached(now, pumpStopAt)) {
    pumpRunning = false; setPump(false); logEvent("WATER_END", "0");
  }
}

void updateSync(unsigned long now) {
  if (syncIntervalMs == 0) return;
  if (nextSyncAt == 0) nextSyncAt = now + syncIntervalMs;
  if (timeReached(now, nextSyncAt)) {
    digitalWrite(syncTtlPin, HIGH);
    syncTtlOffAt = now + ttlPulseMs;
    nextSyncAt += syncIntervalMs;
    // TTL 脉冲照发，但不打串口日志（减少刷屏）
  }
}

void updateTtls(unsigned long now) {
  if (rewardTtlOffAt && timeReached(now, rewardTtlOffAt)) { digitalWrite(rewardTtlPin, LOW); rewardTtlOffAt = 0; }
  if (lickTtlOffAt   && timeReached(now, lickTtlOffAt))   { digitalWrite(lickTtlPin, LOW);   lickTtlOffAt = 0; }
  if (syncTtlOffAt   && timeReached(now, syncTtlOffAt))   { digitalWrite(syncTtlPin, LOW);   syncTtlOffAt = 0; }
  if (cueTtlOffAt    && timeReached(now, cueTtlOffAt))    { digitalWrite(cueTtlPin, LOW);    cueTtlOffAt = 0; }
}

// ═══════════════════════════════════════════════════
// TTL 脉冲
// ═══════════════════════════════════════════════════

void pulseRewardTtl(unsigned long now) { digitalWrite(rewardTtlPin, HIGH); rewardTtlOffAt = now + ttlPulseMs; }
void pulseLickTtl(unsigned long now)   { digitalWrite(lickTtlPin, HIGH);   lickTtlOffAt   = now + ttlPulseMs; }
void pulseCueTtl(unsigned long now)    { digitalWrite(cueTtlPin, HIGH);    cueTtlOffAt    = now + ttlPulseMs; }

// ═══════════════════════════════════════════════════
// 泵 / LED
// ═══════════════════════════════════════════════════

void setPump(bool on) { digitalWrite(pumpPin, on ? HIGH : LOW); digitalWrite(ledPin, on ? HIGH : LOW); }

void setAllTtlsLow() {
  digitalWrite(rewardTtlPin, LOW); digitalWrite(lickTtlPin, LOW);
  digitalWrite(syncTtlPin, LOW);   digitalWrite(cueTtlPin, LOW);
}

// ═══════════════════════════════════════════════════
// 工具函数
// ═══════════════════════════════════════════════════

bool timeReached(unsigned long now, unsigned long target) { return (long)(now - target) >= 0; }

const char* statusText() {
  static char buf[80];
  snprintf(buf, sizeof(buf), "dose_ms=%lu,pump=%d,mpr121=%d,sync_ms=%lu",
           doseMs, digitalRead(pumpPin), mpr121Ready, syncIntervalMs);
  return buf;
}

void logEvent(const char* eventName, const char* value) {
  Serial.print(millis()); Serial.print(",");
  Serial.print(eventName); Serial.print(",");
  Serial.println(value);
}

void printHelp() {
  Serial.println(F("Commands: WATER [ms], DOSE ms, PUMP ON/OFF, STOP, TTLMS ms, SYNCMS ms,"));
  Serial.println(F("  CUE, WINDOW dur reward, WINDOW_STOP, MDEBUG, REGDUMP,"));
  Serial.println(F("  THR t r      (touch/release threshold, lower=more sensitive)"));
  Serial.println(F("  DMIN min     (software confirm delta, default 5)"));
  Serial.println(F("  RESETMPR     (re-init MPR121)"));
  Serial.println(F("  STATUS, HELP"));
}

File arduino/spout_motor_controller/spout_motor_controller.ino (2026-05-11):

// Nano for the motor mounted on the manual Z-stage water-spout module.
// The Z-stage itself is adjusted manually; this motor only drives the mounted
// spout/module mechanism.
// Keeps the original pins from your working sketch.

const byte stepPin = 2;
const byte dirPin = 3;
const byte enablePin = 4;
const bool enableActiveLow = false;

unsigned int stepDelayUs = 2000;
long positionSteps = 0;
long targetSteps = 0;
bool movingToTarget = false;
int jogDirection = 0;
unsigned long lastStepAt = 0;

String line;

void setup() {
  pinMode(stepPin, OUTPUT);
  pinMode(dirPin, OUTPUT);
  pinMode(enablePin, OUTPUT);
  digitalWrite(stepPin, LOW);
  digitalWrite(dirPin, LOW);
  setEnabled(true);

  Serial.begin(115200);
  while (!Serial) {}
  Serial.println("READY,SPOUT_MOTOR");
  printHelp();
}

void loop() {
  readSerial();
  updateMotion();
}

void readSerial() {
  while (Serial.available() > 0) {
    char c = (char)Serial.read();
    if (c == '\n' || c == '\r') {
      if (line.length() > 0) {
        handleCommand(line);
        line = "";
      }
    } else {
      line += c;
      if (line.length() > 80) line = "";
    }
  }
}

void handleCommand(String cmd) {
  cmd.trim();
  cmd.toUpperCase();

  if (cmd == "HELP") {
    printHelp();
  } else if (cmd == "STATUS") {
    logEvent("STATUS", String(positionSteps));
  } else if (cmd == "ZERO") {
    positionSteps = 0;
    targetSteps = 0;
    movingToTarget = false;
    logEvent("ZERO", "0");
  } else if (cmd == "STOP" || cmd == "S") {
    jogDirection = 0;
    movingToTarget = false;
    logEvent("STOP", String(positionSteps));
  } else if (cmd == "ENABLE" || cmd == "EN") {
    setEnabled(true);
    logEvent("ENABLE", "1");
  } else if (cmd == "DISABLE" || cmd == "DIS") {
    setEnabled(false);
    logEvent("ENABLE", "0");
  } else if (cmd == "F") {
    startJog(1);
  } else if (cmd == "B") {
    startJog(-1);
  } else if (cmd.startsWith("JOG ")) {
    int dir = cmd.endsWith("B") ? -1 : 1;
    startJog(dir);
  } else if (cmd.startsWith("STEP ")) {
    long delta = parseLongAfterSpace(cmd, 0);
    targetSteps = positionSteps + delta;
    movingToTarget = true;
    jogDirection = 0;
    logEvent("STEP_TARGET", String(targetSteps));
  } else if (cmd.startsWith("GOTO ")) {
    targetSteps = parseLongAfterSpace(cmd, positionSteps);
    movingToTarget = true;
    jogDirection = 0;
    logEvent("GOTO_TARGET", String(targetSteps));
  } else if (cmd.startsWith("SPEED ")) {
    long value = parseLongAfterSpace(cmd, stepDelayUs);
    if (value >= 100 && value <= 20000) {
      stepDelayUs = (unsigned int)value;
      logEvent("SPEED_US", String(stepDelayUs));
    } else {
      logEvent("ERR", "SPEED_RANGE_100_20000");
    }
  } else {
    logEvent("ERR", "UNKNOWN_COMMAND");
  }
}

void updateMotion() {
  int dir = 0;
  if (jogDirection != 0) {
    dir = jogDirection;
  } else if (movingToTarget) {
    if (targetSteps == positionSteps) {
      movingToTarget = false;
      logEvent("MOVE_DONE", String(positionSteps));
      return;
    }
    dir = targetSteps > positionSteps ? 1 : -1;
  } else {
    return;
  }

  unsigned long now = micros();
  if (now - lastStepAt >= (unsigned long)stepDelayUs * 2) {
    stepOnce(dir);
    lastStepAt = now;
  }
}

void stepOnce(int dir) {
  digitalWrite(dirPin, dir > 0 ? HIGH : LOW);
  digitalWrite(stepPin, HIGH);
  delayMicroseconds(stepDelayUs);
  digitalWrite(stepPin, LOW);
  positionSteps += dir > 0 ? 1 : -1;
}

void startJog(int dir) {
  setEnabled(true);
  jogDirection = dir;
  movingToTarget = false;
  logEvent("JOG", dir > 0 ? "F" : "B");
}

void setEnabled(bool enabled) {
  if (enableActiveLow) {
    digitalWrite(enablePin, enabled ? LOW : HIGH);
  } else {
    digitalWrite(enablePin, enabled ? HIGH : LOW);
  }
}

long parseLongAfterSpace(String cmd, long fallback) {
  int idx = cmd.indexOf(' ');
  if (idx < 0) return fallback;
  return cmd.substring(idx + 1).toInt();
}

void logEvent(String eventName, String value) {
  Serial.print(millis());
  Serial.print(",");
  Serial.print(eventName);
  Serial.print(",");
  Serial.println(value);
}

void printHelp() {
  Serial.println("Commands: STEP signed_steps, GOTO pos, F, B, JOG F, JOG B, STOP, ENABLE, DISABLE, SPEED us, ZERO, STATUS, HELP");
  Serial.println("CSV events: arduino_ms,event,value");
}

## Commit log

2026-05-11 初始版本：头部固定行为实验控制装置 v1.0
    - Water Nano 固件：蠕动泵/MPR121舔水检测/4路TTL/自治窗口模式
    - Motor Nano 固件：步进电机控制/位置追踪
    - Python GUI：协议引擎/面板控制/舔水可视化/事件日志
    - Bpod MATLAB 协议：HiFi 8kHz cue 触发
    - 完整接线文档和硬件清单
    [给水1.0外壳.SLDPRT]
2026-05-11 存档：摄像头预览功能、电机使能逻辑修复、MPR121测试前版本
2026-05-11 存档：MPR121软件舔水检测、I2C双地址兼容、电机使能修复
2026-05-11 存档：舔水去抖锁存机制、舔水图表重写、中文字体、飞书通知配置
2026-05-11 存档：Nano死机修复 + 状态面板 + 智能补水 + 多舔标记 + 时间线优化
    - Arduino: String→char[]防堆碎片，移除泵后I2C阻塞，新增RESETMPR命令
    - 协议: 智能补水(上次MISS跳过泵)，ITI舔水追踪，多舔记录
    - GUI: 新增状态面板(9格实时状态)，Task设置改名，SYNC过滤
    - 时间线: 单轴显示，首次舔●/后续舔○/ITI舔○，Cue标记
    - 布局: PanedWindow可拖拽分割线，COM口宽度固定
    [device_control_app.py, gui_panels.py, lick_plot.py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]
2026-05-11 存档：Nano看门狗+心跳自动重连+时间线精准对齐+智能补水完善
    - Arduino: AVR硬件看门狗500ms超时自动复位，SYNC不刷串口，I2C降频+错误恢复
    - Python: 3s心跳检测+8s无响应自动重连，事件解析加固strip，15ms轮询
    - 协议: 智能补水改为(MISS且ITI无舔)才跳过，200ms宽容窗口防边界遗漏
    - 时间线: window_s精准匹配参数，500ms脏标刷新，轴超出5s不拥挤
    - UI: PanedWindow全可拖拽，状态面板10pt彩色圆点可视化，SimHei中文字体
2026-05-12 存档：Session数据保存修复 + UI细节优化
    - Bug修复: session.json trials不再为空，试次结果正确传入DataManager
    - Bug修复: 过滤session.json中precue_ms/post_reward_ms等废弃参数
    - UI: 问号tooltip拆分为独立小号灰色标记，与其他标签样式一致
    [events.csv]
2026-05-12 gitignore: 排除实验数据目录 data/
    [events.csv]
